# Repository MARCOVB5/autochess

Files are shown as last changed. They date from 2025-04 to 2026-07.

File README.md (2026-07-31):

# AutoChess

AutoChess é um protótipo de tabuleiro de MiniChess 4×4 capaz de jogar fisicamente
contra uma pessoa. O sistema combina visão computacional para reconhecer a jogada
humana, uma IA baseada em Q-learning para escolher a resposta e uma estrutura CNC
CoreXY com eletroímã para movimentar as peças.

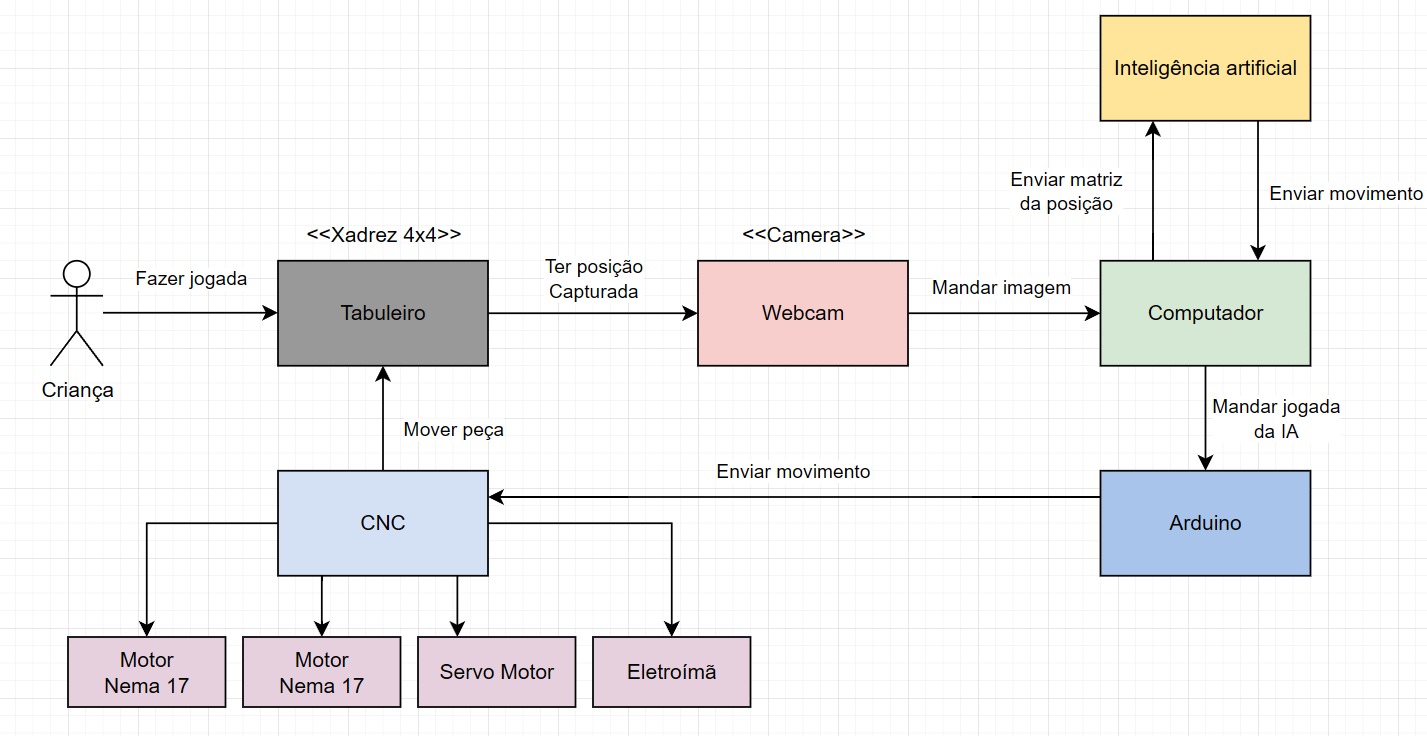
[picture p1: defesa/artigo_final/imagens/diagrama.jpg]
Diagrama geral do AutoChess


## Como funciona

O fluxo de uma partida é:

1. a pessoa movimenta uma peça branca no tabuleiro;
2. a câmera captura uma imagem do estado atual;
3. o módulo de visão computacional identifica as peças e deduz a jogada;
4. o motor de MiniChess valida o movimento;
5. a IA escolhe uma jogada para as peças pretas;
6. o controlador converte a jogada em comandos para a CNC, que move a peça.

O jogo utiliza um tabuleiro 4×4 com peões, torres, rainhas e reis. As peças brancas
são controladas pela pessoa e as pretas pela IA.

## Componentes

- **Motor de jogo:** regras, validação de jogadas, xeque, xeque-mate e empate.
- **Inteligência artificial:** agente de Q-learning tabular com avaliação heurística
  de uma jogada.
- **Visão computacional:** OpenCV para localizar o tabuleiro e classificar as peças.
- **Controle físico:** comunicação serial com Arduino e envio de comandos G-code.
- **Simuladores:** interfaces gráficas em Pygame para partidas locais, com ou sem IA.
- **Estrutura mecânica:** modelos do tabuleiro, peças e componentes para fabricação.

## Estrutura do repositório

```text
.
├── core/                         # Aplicação integrada e módulos principais
│   ├── main.py                   # Fluxo câmera → IA → CNC
│   ├── unified_app.py            # Painel visual integrado do robô
│   ├── button_reader.py          # Eventos dos botões físicos
│   ├── hardware_config.py        # Câmera, serial, comandos e coordenadas físicas
│   ├── minichess.py              # Regras do MiniChess 4×4
│   ├── ai_player.py              # Agente de Q-learning
│   ├── train_ai.py               # Treinamento da IA por simulação
│   ├── cv/                       # Visão computacional e imagens de treino/teste
│   ├── models/                   # Modelo persistido da IA
│   └── serial_cnc/               # Controlador serial e firmware do Arduino
├── minichess_simulator/
│   ├── minichess/                # Simulador pessoa contra pessoa
│   └── minichess_ia/             # Simulador pessoa contra IA
├── modelos/                      # Arquivos 3D e modelos do tabuleiro
├── proposta/                     # Propostas e documentação do projeto
└── defesa/                       # Artigo, apresentação e vídeo
```

## Requisitos

Para executar o software:

- Python 3;
- uma webcam compatível com OpenCV;
- Arduino conectado por USB e programado com o firmware do projeto;
- mecanismo CNC/CoreXY com servo e eletroímã.

Os simuladores gráficos não precisam do hardware físico.

## Instalação

Clone o repositório e crie um ambiente virtual:

```bash
git clone <URL-DO-REPOSITORIO>
cd autochess
python3 -m venv .venv
source .venv/bin/activate
python -m pip install --upgrade pip
python -m pip install -r core/requirements.txt
```

No Windows, ative o ambiente com:

```powershell
.venv\Scripts\activate
```

## Executando o sistema completo

Conecte a câmera e o Arduino, posicione o mecanismo na origem configurada e execute
a aplicação a partir da pasta `core`:

```bash
cd core
python main.py
```

A aplicação procura automaticamente a CNC nas portas seriais disponíveis. Índice e
orientação da câmera, porta serial, comandos do firmware, velocidade e coordenadas
da CNC ficam centralizados em `core/hardware_config.py`. Use `SERIAL_PORT = None`
para autodetecção ou informe explicitamente uma porta como `/dev/ttyUSB0` ou
`COM3`.

Durante a partida, use:

- `0` para capturar e processar a jogada;
- `1` para iniciar uma nova partida;
- `2` para apagar o aprendizado salvo e reiniciar a IA;
- `q` para encerrar.

### Painel unificado

O painel reúne o tabuleiro lógico, a última imagem processada pelo CV, a IA, a
CNC e os botões físicos:

```bash
cd core
python unified_app.py
```

Configure `SERIAL_PORT` para a CNC e `BUTTONS_SERIAL_PORT` para o Arduino dos
botões em `hardware_config.py`. As portas devem ser diferentes. Os botões enviam
`BUTTON_0`, `BUTTON_1` e `BUTTON_2`; mouse e teclado executam os mesmos comandos.

Para testar toda a interface e jogar contra a IA sem hardware:

```bash
python unified_app.py --simulate
```

Também é possível abrir uma imagem no painel de CV durante a simulação:

```bash
python unified_app.py --simulate \
  --cv-image cv/assets/storage/testing-chessboards/chessboard_allpieces.jpg
```

Use `--no-camera`, `--no-cnc` ou `--no-buttons` para testar apenas partes da
montagem.

> **Atenção:** antes do primeiro movimento, confira a origem, os limites e o sentido
> dos eixos da CNC. Revise `core/hardware_config.py` sempre que mudar a montagem,
> a câmera ou o firmware.

## Executando os simuladores

### Pessoa contra pessoa

```bash
cd minichess_simulator/minichess
python -m pip install -r ../../core/requirements.txt
python main.py
```

### Pessoa contra IA

```bash
cd minichess_simulator/minichess_ia
python -m pip install -r requirements.txt
python main.py
```

Nas interfaces, selecione uma peça com o mouse e clique em uma das casas destacadas
para realizar a jogada.

## Treinando a IA

O agente pode ser treinado sem câmera ou CNC, enfrentando um oponente aleatório:

```bash
cd core
python train_ai.py --games 1000 --seed 0
```

Por padrão, o modelo é salvo em `core/models/minichess_ai_model.pkl`. Use
`--model caminho/do/modelo.pkl` para escolher outro arquivo e `--max-plies` para
limitar a duração de cada partida simulada.

## Testes

Os testes do motor, da IA e do painel usam `unittest`:

```bash
cd core
python -m unittest test_ai.py test_unified_app.py
```

Também há scripts experimentais de câmera, visão e CNC em `core/test_*.py`,
`core/cv/` e `core/serial_cnc/`. Alguns deles dependem do hardware conectado e da
calibração do protótipo.

## Firmware

Os sketches usados pelo controlador estão em:

- `core/serial_cnc/arduino-cli/firmware_hibrido/firmware_hibrido.ino`;
- `core/serial_cnc/arduino-cli/grblUpload/grblUpload.ino`.

Grave no Arduino o firmware adequado à montagem antes de iniciar a aplicação
integrada. A comunicação serial utiliza `115200` baud por padrão.

## Documentação e materiais

- Artigo final: `defesa/artigo_final/output/main.pdf`;
- apresentação: `defesa/apresentacao/main.pdf`;
- vídeo do projeto: `defesa/video/video_autochess.mp4`;
- modelos para fabricação: `modelos/`.

## Estado do projeto

Este repositório contém um protótipo acadêmico. A precisão da visão computacional e
as coordenadas da CNC dependem da iluminação, do posicionamento da câmera e da
calibração mecânica de cada montagem.

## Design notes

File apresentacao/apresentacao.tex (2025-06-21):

\documentclass{beamer}

\usetheme{Madrid}  % Claro, limpo e com bom contraste

\usepackage[utf8]{inputenc}
\usepackage[absolute,overlay]{textpos} % no preâmbulo
\usepackage[T1]{fontenc}
\usepackage[brazil]{babel}
\usepackage{graphicx}
\usepackage[linesnumbered]{algorithm2e} % sem ruled, sem vlined
\usepackage{tikz}
\usetikzlibrary{shapes.geometric, arrows.meta, positioning}
\tikzstyle{startstop} = [rectangle, rounded corners, minimum width=2.8cm, minimum height=1cm,text centered, draw=black, fill=blue!20]
\tikzstyle{process} = [rectangle, minimum width=2.8cm, minimum height=1cm, text centered, draw=black, fill=gray!10]
\tikzstyle{decision} = [diamond, minimum width=3cm, minimum height=1cm, text centered, draw=black, fill=orange!20]
\tikzstyle{arrow} = [thick, ->, >=stealth]

\setbeamertemplate{footline}[frame number] % Numeração dos slides
\setbeamertemplate{navigation symbols}{}    % Remove os ícones padrão do Beamer

\title{Autochess}
\author{Fernando F. Vieira \\ Gabriel A. B. Caballero \\ Marco V. Busetti}
\institute{Oficina de Integração 1 (ELEX20) \\ Engenharia de Computação - UTFPR}
\date{\today}

% Configura aparência das páginas de seção
\AtBeginSection[]{
  \begin{frame}[plain]
    \frametitle{\insertsectionhead}
    \tableofcontents[currentsection]
  \end{frame}
}

\begin{document}

% Slide de capa
\frame{\titlepage}

% (Opcional) Índice da apresentação
\begin{frame}{Roteiro da Apresentação}
  \tableofcontents
\end{frame}

\section{Introdução}

\begin{frame}{Escopo e Objetivos}
\begin{itemize}
    \item O projeto \textbf{Autochess} foi desenvolvido com propósito pedagógico: introduzir conceitos de \textbf{Machine Learning} e \textbf{xadrez} para crianças.
    
    \item Utiliza um \textbf{tabuleiro 4x4} simplificado, composto por:
        \begin{itemize}
        \item Módulo de \textbf{Inteligência Artificial}.
        \item Módulo de \textbf{Visão Computacional}.
        \item Sistema \textbf{CNC}.
    \end{itemize}
\end{itemize}
\end{frame}

\begin{frame}[plain]{Diagrama de blocos}
  \centering

\end{frame}

\begin{frame}[plain]{Idealização do projeto}
  \centering
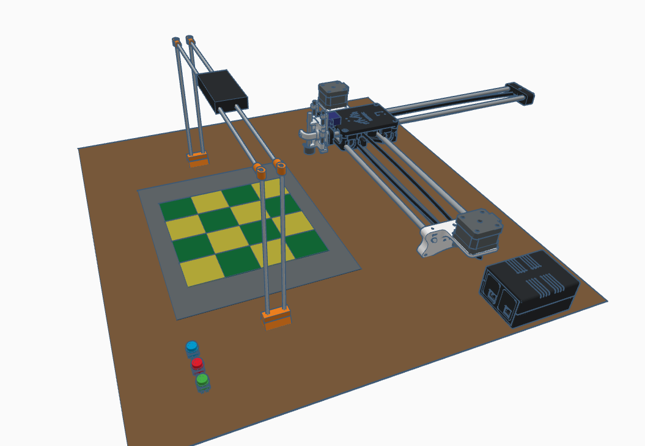
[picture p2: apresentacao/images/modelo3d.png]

\end{frame}

\begin{frame}{Materiais e Orçamento}
  \begin{tabular}{|l|c|c|}
    \hline
    \textbf{Item} & \textbf{Quantidade} & \textbf{Preço (R\$)} \\
    \hline
    Arduino Uno & 2 & 40,00 \\
    Shield CNC V3 + Drivers & 1 & 15,00 \\
    Eletroimã & 1 & 6,00 \\
    Nema 17 & 2 & 40,00 \\
    Servo motor SG90 & 1 & 5,00 \\
    Placa universal & 1 & 12,00 \\
    Patolas & 2 & 30,00 \\
    Fonte de alimentação & 2 & 50,00 \\
    Webcam Full HD & 1 & 50,00 \\
    Impressão 3D & - & 100,00 \\
    Base MDF & - & 40,00 \\
    Outros (fios, conectores, etc) & - & 30,00 \\
    \hline
    \textbf{Total} & & \textbf{418,00} \\
    \hline
  \end{tabular}
   \vspace{0.5em}

  {\scriptsize\textit{Observação: Componentes eletrônicos adquiridos via \href{https://pt.aliexpress.com}{AliExpress}.}}
\end{frame}

% Seção 1
\section{Hardware}

\begin{frame}[plain]{Idealização do projeto elétrico}
  \centering
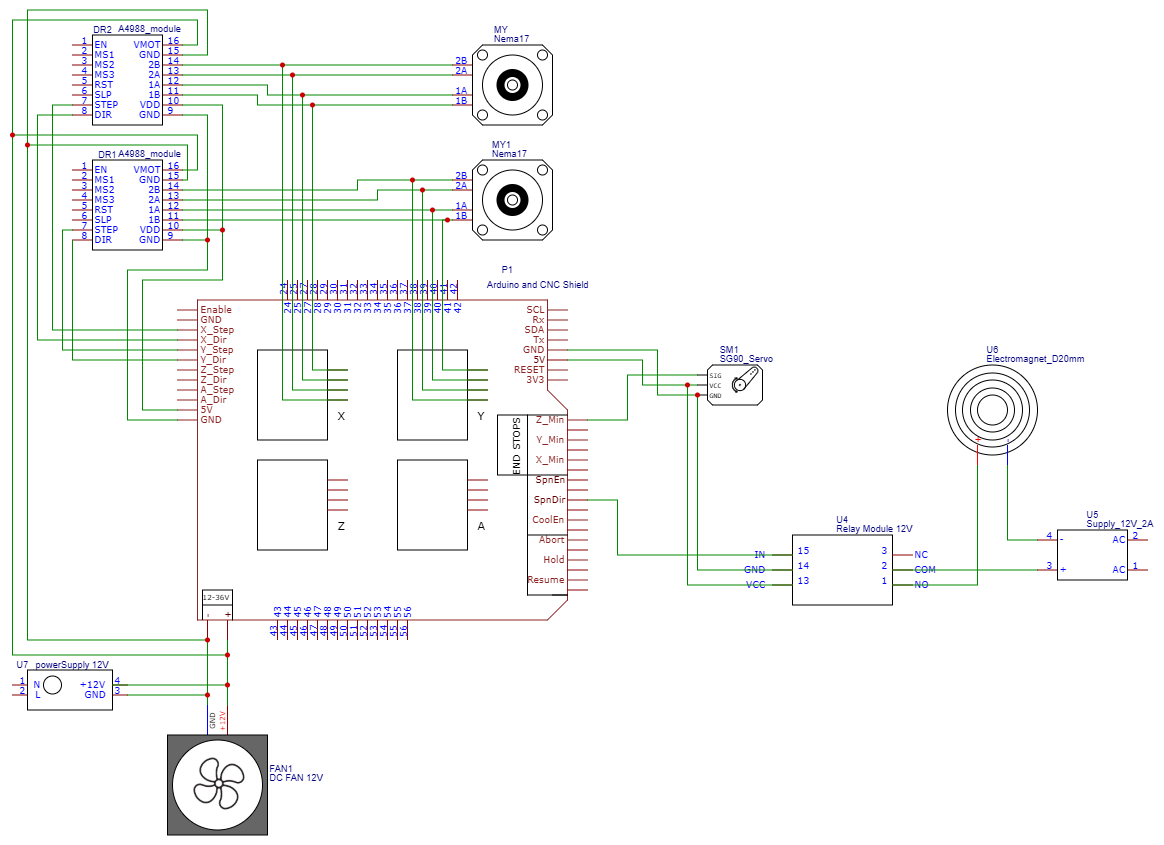
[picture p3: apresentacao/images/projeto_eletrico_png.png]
  
\end{frame}

\begin{frame}[plain]{Idealização do projeto elétrico}
  \centering
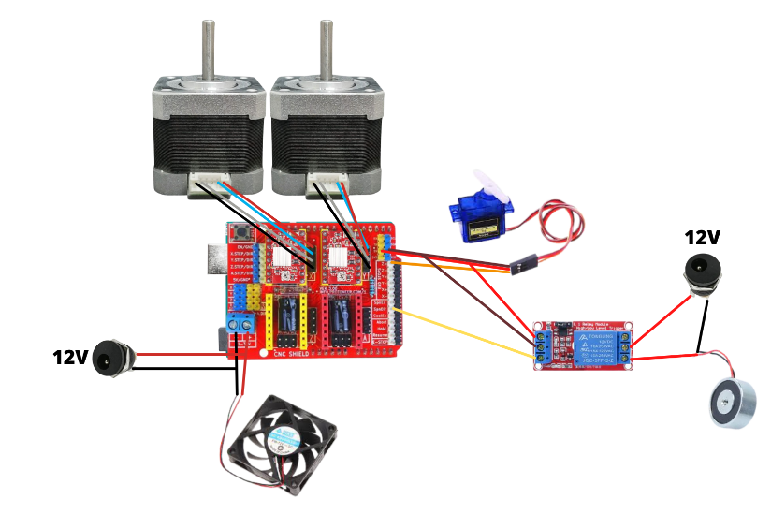
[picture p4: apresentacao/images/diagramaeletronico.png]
  
\end{frame}

\begin{frame}[plain]{Algumas modificações...}
\begin{itemize}
    \item Foram utilizados \textbf{2 Arduinos UNO}.
    \item Tarefas de cada um:
    \begin{itemize}
        \item \textbf{Arduino 1}: Controle da CNC (\textit{firmware} GRBL-servo);
        \item \textbf{Arduino 2}: Receber input dos botões.
    \end{itemize}
\end{itemize}
\end{frame}

\begin{frame}{Controle e Firmware}
  \begin{itemize}
    \item Utilizado o \textbf{firmware GRBL-servo}, baseado no repositório da \textbf{Robottini}\textsuperscript{\ref{grbl-servo-link}}.
    \item GRBL é um firmware open-source que interpreta comandos \texttt{G-code} para controle de CNCs.
    \item Permitiu o \textbf{controle dos motores de passo}, \textbf{eletroímã} e \textbf{servomotor} com precisão.
    \item Foram realizadas algumas modificações no código fonte do firmware para adaptar o ângulo de abertura do servomotor.
  \end{itemize}

  \vfill
  \begin{flushright}
    \scriptsize \textsuperscript{\refstepcounter{footnote}\label{grbl-servo-link}\thefootnote} \href{https://github.com/robottini/grbl-servo}{https://github.com/robottini/grbl-servo}
  \end{flushright}
\end{frame}

% Seção 3
\section{Mecânica}

\begin{frame}{Estrutura CoreXY}
  \begin{figure}
    \centering
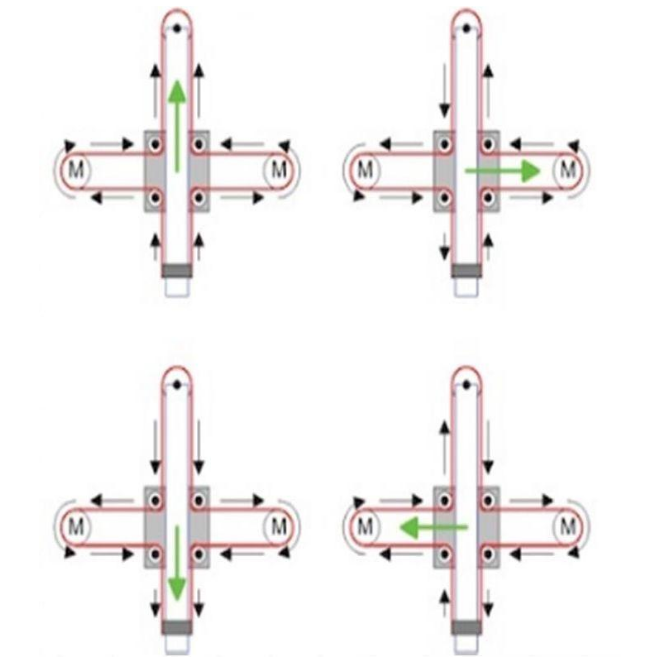
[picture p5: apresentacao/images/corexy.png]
    
    \caption{Estrutura cruzada CoreXY}
      \vspace{0.3em}
  {\small \textit{Fonte:} \href{test3dprints.com}{test3dprints.com}}
    \label{fig:enter-label}
\end{figure}
\end{frame}

\begin{frame}{CoreXY - Princípio de Funcionamento}
\begin{itemize}
  \item Os motores estão fixos na estrutura.
  \item O movimento é transmitido por apenas uma correia e polias dispostas em padrão cruzado.
  \item Os motores atuam juntos para gerar os deslocamentos nos eixos.
\end{itemize}
\end{frame}

\begin{frame}{Vantagens do CoreXY}
\begin{itemize}
  \item Cabeçote leve (motores não se movem junto).
  \item Alta velocidade e aceleração.
  \item Estrutura simétrica e eficiente no uso do espaço.
  \item Redução de inércia no movimento.
  \item Uso de apenas uma correia.
\end{itemize}
\end{frame}

\begin{frame}{Estrutura física do projeto}
  \begin{itemize}
    \item Para o suporte da CNC foi utilizado como base o projeto \textbf{DrawingBot} da \textbf{MakerC}\textsuperscript{\ref{drawingbot-link}}.
    \item Arquivos para impressão 3D disponibilizados foram utilizados.
    \item Todos os objetos são apoiados em uma base de MDF cortada à laser.
    \item Fora a estrutura impressa 3D da CNC (já pronta), todos os outros objetos (peças de xadrez, suporte para câmera, etc.) foram modelados à parte.
  \end{itemize}

  \vfill
  \begin{flushright}
    \scriptsize \textsuperscript{\refstepcounter{footnote}\label{drawingbot-link}\thefootnote} \href{https://www.thingiverse.com/thing:1517211}{https://www.thingiverse.com/thing:1517211}
  \end{flushright}
\end{frame}

\begin{frame}{Modelo da base do MDF}
  \centering
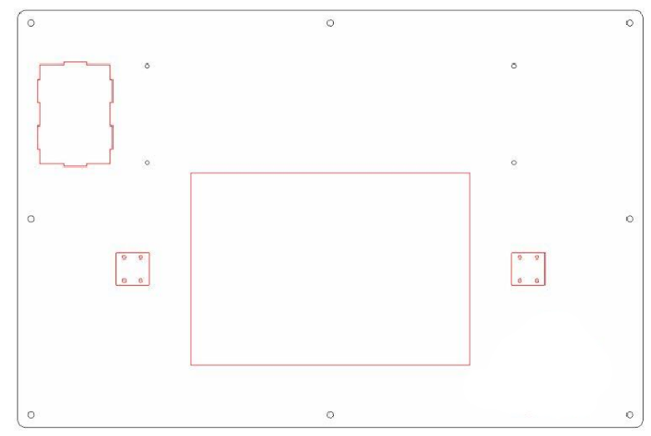
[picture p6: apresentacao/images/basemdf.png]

\end{frame}

\begin{frame}{Modelos 3D - suporte para câmera}
  \centering
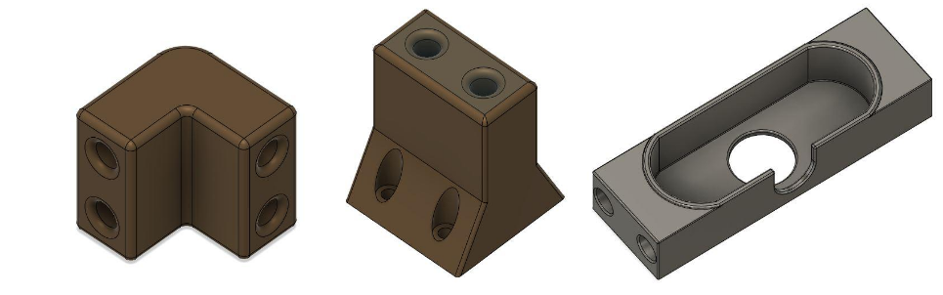
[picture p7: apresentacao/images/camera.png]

\end{frame}

\begin{frame}{Modelos 3D - peças do xadrez}
  \centering
  \begin{minipage}{0.48\textwidth}
    \centering
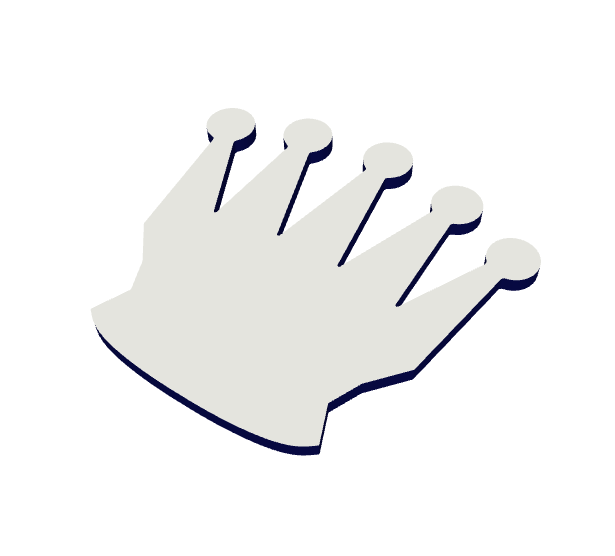
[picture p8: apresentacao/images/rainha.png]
    
    \caption{Rainha}
  \end{minipage}
  \hfill
  \begin{minipage}{0.48\textwidth}
    \centering
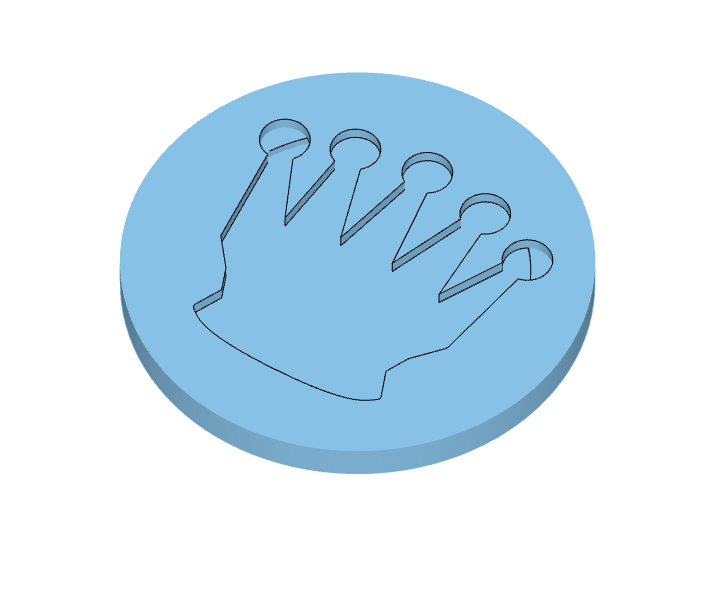
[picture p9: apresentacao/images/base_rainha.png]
    
    \caption{Base da Rainha}
  \end{minipage}
\end{frame}

\section{Software}

\begin{frame}{Minichess 4×4 – Variante Silverman}
\begin{itemize}
  \item \textbf{Minichess} é uma \textbf{família de variantes} do xadrez tradicional, jogadas em tabuleiros menores.
  \item A variante \textbf{Silverman 4×4} é jogada com as seguintes peças:
  \begin{itemize}
    \item Rei, torre, rainha e peões.
  \end{itemize}
  \item Útil para estudo de algoritmos, resolução de jogos e IA aplicada.
\end{itemize}
\end{frame}

\begin{frame}{Minichess 4×4 – Variante Silverman}
  \begin{figure}
    \centering
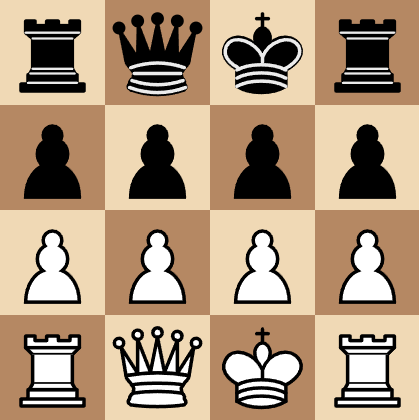
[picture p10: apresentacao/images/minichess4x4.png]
    
    \caption{Silverman 4x4}
      \vspace{0.3em}
  {\small \textit{Fonte:} \href{https://en.wikipedia.org/wiki/Minichess}{https://en.wikipedia.org/wiki/Minichess}}
    \label{fig:enter-label}
\end{figure}
\end{frame}

\begin{frame}{IA com Q-Learning no Silverman 4×4}
\begin{itemize}
  \item Modelamos o jogo como um \textbf{Processo de Decisão de Markov (MDP)}:
  \begin{itemize}
    \item \textbf{Estados} (\( S \)): todas as possíveis configurações do tabuleiro.
    \item \textbf{Ações} (\( A \)): todos os movimentos legais em um dado estado.
    \item \textbf{Recompensa} (\( R \)): +1 para vitória, 0 para empate, -1 para derrota.
  \end{itemize}
  \item Utilizamos \textbf{Q-Learning}, um algoritmo off-policy de aprendizagem por reforço:
  \[
  Q(s,a) \leftarrow Q(s,a) + \alpha \left[ r + \gamma \max_{a'} Q(s',a') - Q(s,a) \right]
  \]
  \item Estratégia \textbf{$\varepsilon$-gulosa} para equilibrar \textit{exploration \& exploitation}:
  \[
  \text{Escolhe melhor ação com probabilidade } 1 - \varepsilon, \text{ aleatória com } \varepsilon
  \]
\end{itemize}
\end{frame}

\begin{frame}{Parâmetros do Q-Learning e $\varepsilon$-gulosa}
\begin{itemize}
  \item \textbf{Taxa de aprendizado} \(\alpha\): \\
        \(\rightarrow\) Valor utilizado: \(\alpha = 0.5\).
  
  \item \textbf{Fator de desconto} \(\gamma\):  \\
        \(\rightarrow\) Valor utilizado: \(\gamma = 0.9\).
  
  \item \textbf{Taxa de exploração} \(\varepsilon\) (estratégia $\varepsilon$-gulosa): \\
        \(\rightarrow\) Inicialmente alta (ex: 0.9), decresce ao longo do treinamento para valores baixos (ex: 0.1 ou 0.01).
\end{itemize}
\end{frame}

\begin{frame}[fragile]{Q-Learning}
\begin{center}
\begin{minipage}{0.85\linewidth} % ajusta a largura do algoritmo
\begin{algorithm}[H]
\DontPrintSemicolon
\textcolor{blue}{\textbf{Inicializar}} $Q(s, a)$ arbitrariamente\;
\For{\textcolor{purple}{\textbf{cada episódio}} (partida)}{
    \textcolor{blue}{\textbf{Inicializar}} estado $s$\;
    \While{\textcolor{red}{\textbf{jogo não terminou}}}{
        \colorbox{yellow!20}{Com probabilidade $\varepsilon$, escolher ação aleatória $a$}\;
        \colorbox{yellow!20}{Caso contrário, escolher $a = \arg\max_{a'} Q(s, a')$}\;
        \textcolor{orange}{\textbf{Executar}} ação $a$, observar recompensa $r$ e novo estado $s'$\;
        \textcolor{green!60!black}{\textbf{Atualizar:}} \\
        \colorbox{green!15}{$Q(s,a) \leftarrow Q(s,a) + \alpha \left[ r + \gamma \max_{a'} Q(s',a') - Q(s,a) \right]$}\;
        $s \leftarrow s'$\;
    }
}
\end{algorithm}
\end{minipage}
\end{center}
\end{frame}

\begin{frame}{Q-Learning}
\begin{center}
\scalebox{0.8}{ % Reduz o tamanho geral do fluxograma
\begin{tikzpicture}[node distance=1.2cm and 1.7cm]
\tikzstyle{startstop} = [rectangle, rounded corners, minimum width=2.5cm, minimum height=0.9cm, text centered, draw=black, fill=blue!20, font=\small]
\tikzstyle{process}   = [rectangle, minimum width=2.5cm, minimum height=0.9cm, text centered, draw=black, fill=gray!10, font=\small]
\tikzstyle{decision}  = [diamond, minimum width=2.6cm, minimum height=0.9cm, text centered, draw=black, fill=orange!20, font=\small]
\tikzstyle{arrow}     = [thick, ->, >=stealth]

\node (start)  [startstop] {Início do Episódio};
\node (init)   [process, below of=start] {Inicializa $s$};
\node (check)  [decision, below of=init, yshift=-0.9cm] {Fim do jogo?};
\node (action) [process, right of=check, xshift=3.5cm] {Escolhe ação $a$};
\node (step)   [process, below of=action] {Executa $a$, observa $r$, $s'$};
\node (update) [process, below of=step] {Atualiza $Q(s,a)$};
\node (loop)   [process, below of=update] {$s \leftarrow s'$};
\node (end)    [startstop, below of=check, yshift=-3.8cm] {Fim do Episódio};

% Setas principais
\draw [arrow] (start) -- (init);
\draw [arrow] (init) -- (check);

% Seta "não" - usando anchors específicos para evitar sobreposição
\draw [arrow] (check.east) -- node[above] {\footnotesize não} (action.west);

% Setas do loop principal
\draw [arrow] (action) -- (step);
\draw [arrow] (step) -- (update);
\draw [arrow] (update) -- (loop);

% Seta de volta para o check - corrigindo direção da seta
\draw [arrow] (loop.west) -| ++(-4.5,2.4) -| (check.west);

% Seta "sim" - usando anchor específico
\draw [arrow] (check.south) -- node[right] {\footnotesize sim} (end.north);

\end{tikzpicture}
}
\end{center}
\end{frame}

\begin{frame}{Metodologia de Avaliação da IA}
  \begin{itemize}
    \item \textbf{Número de sessões:} 30 sessões distintas, com reinicialização da IA ao início de cada sessão.
    
    \item \textbf{Partidas por sessão:} 20 partidas sequenciais por sessão, totalizando \textbf{600 partidas analisadas}.

    \item \textbf{Métricas utilizadas:}
    \begin{enumerate}
      \item \textbf{Média de jogadas por partida;}
      \item \textbf{Número de blunders;}
      \item \textbf{Saldo de material;}
      \item \textbf{Jogadas seguras (\%).}
    \end{enumerate}
    \item Média de todas sessões de uma determinada partida.
  \end{itemize}
\end{frame}

\begin{frame}[plain]{Q-Learning - Levantamento estatístico sob os resultados}
  \centering
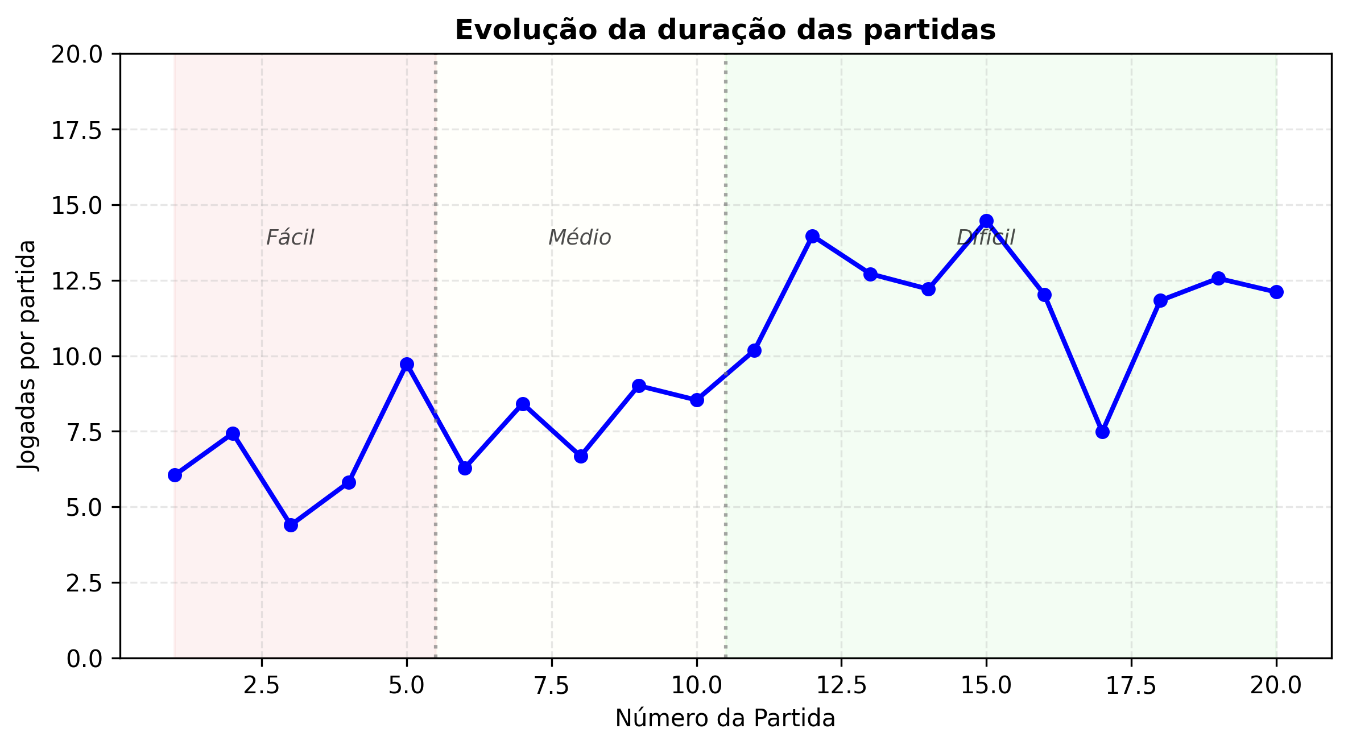
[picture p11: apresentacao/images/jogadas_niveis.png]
  
\end{frame}

\begin{frame}[plain]{Q-Learning - Levantamento estatístico sob os resultados}
  \centering
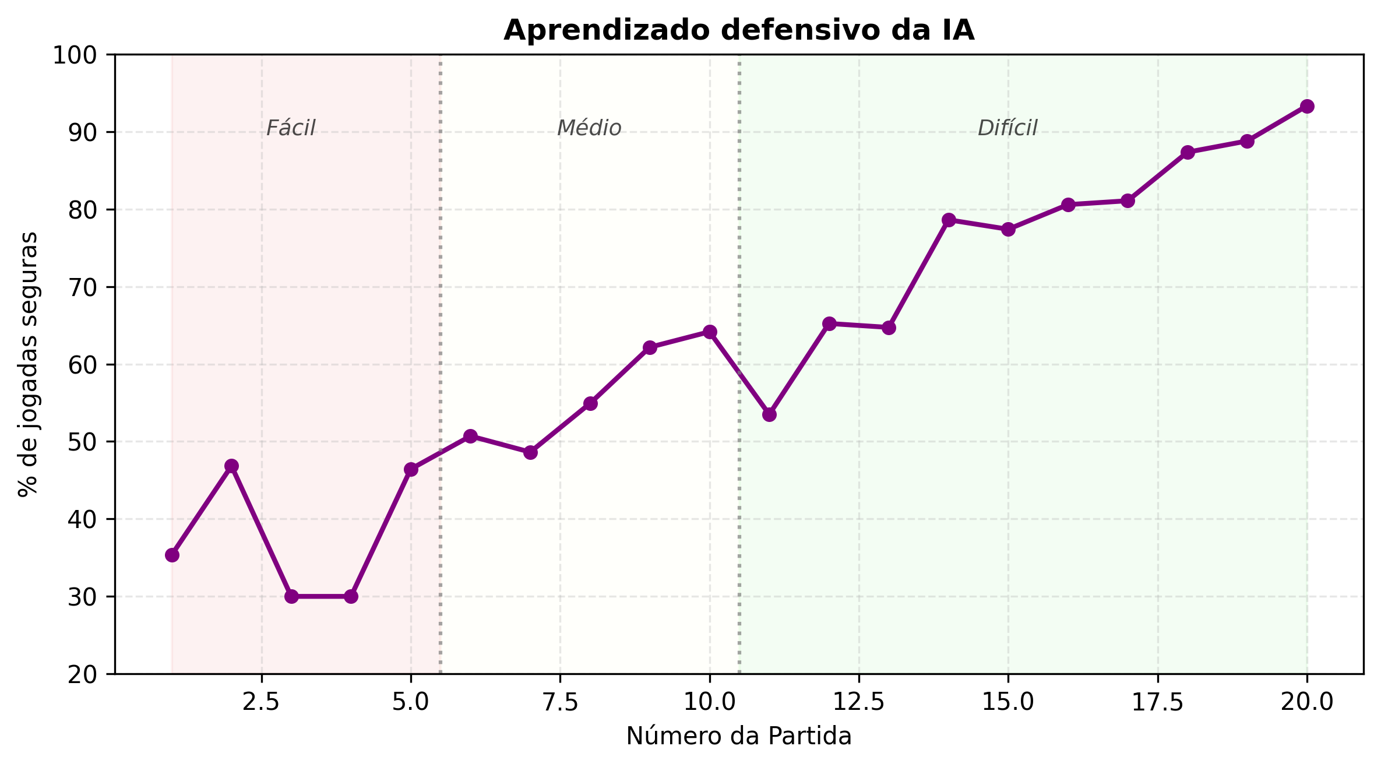
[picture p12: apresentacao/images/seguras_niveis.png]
  
\end{frame}

\begin{frame}[plain]{Q-Learning - Levantamento estatístico sob os resultados}
  \centering
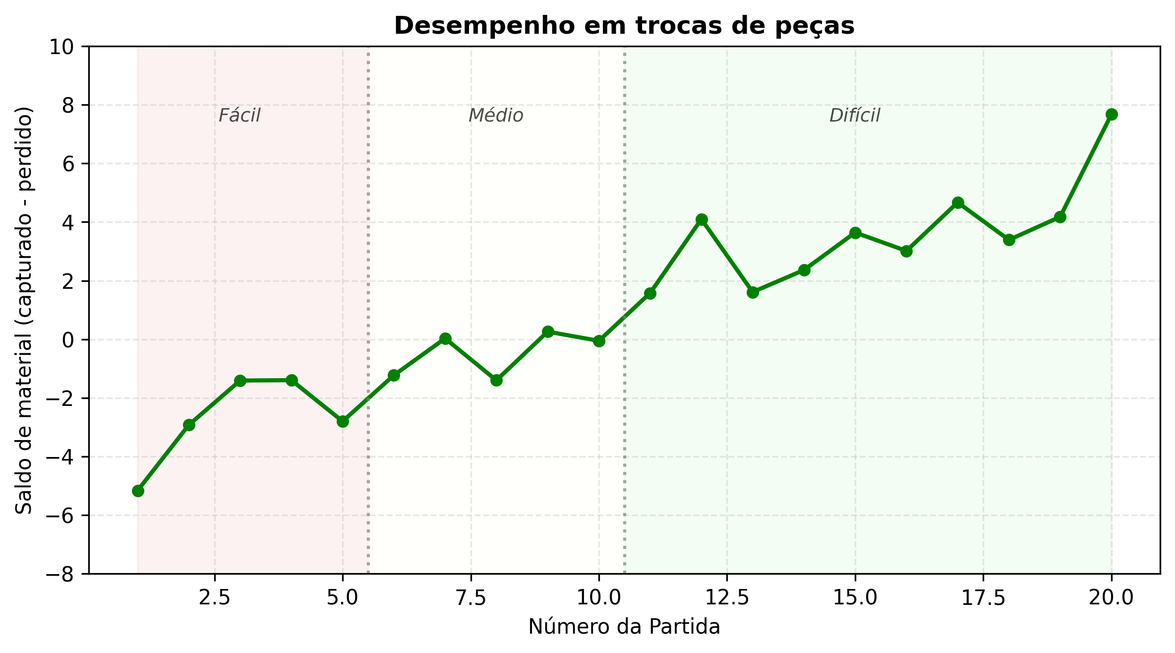
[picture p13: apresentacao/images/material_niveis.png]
  
\end{frame}

\begin{frame}[plain]{Q-Learning - Levantamento estatístico sob os resultados}
  \centering
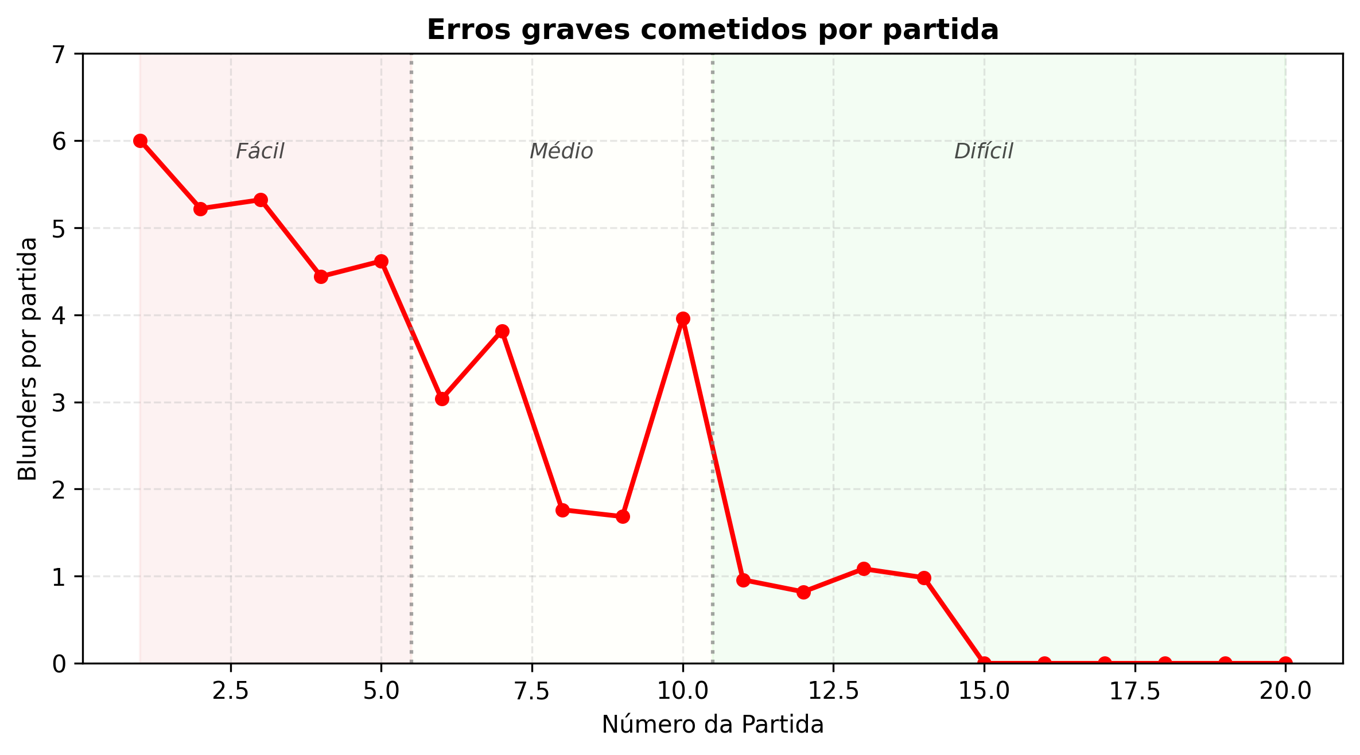
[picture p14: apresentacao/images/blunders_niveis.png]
  
\end{frame}

\begin{frame}{Visão Computacional}
\begin{itemize}
    \item Para identificar o estado do jogo automaticamente, foi necessário utilizar técnicas de visão computacional sobre imagens capturadas por uma câmera fixa.
\end{itemize}
\end{frame}

\begin{frame}{Visão Computacional}
      \begin{alertblock}{Desafios enfrentados}
          \begin{itemize}
        \item Segmentação precisa da área do tabuleiro, mesmo com distorções da câmera.
        \item Diferenciação entre peças brancas e pretas sob diferentes condições de iluminação.
        \item Identificação das peças no tabuleiro, considerando posições variadas.
    \end{itemize}    
  \end{alertblock}
\end{frame}

\begin{frame}{Visão Computacional}
  \begin{exampleblock}{Solução adotada}
        \begin{itemize}
        \item Utilizamos o \textbf{SIFT (Scale-Invariant Feature Transform)} para detecção de pontos-chave robustos.
        \item Detecção de contornos das figuras das peças e extremidades do tabuleiro.
        \item As descrições extraídas com SIFT permitiram realizar \textit{matching} entre peças reais e modelos de referência.
    \end{itemize}
  \end{exampleblock}

\end{frame}

\begin{frame}[plain]{Implementação do SIFT - Exemplos}
  \centering
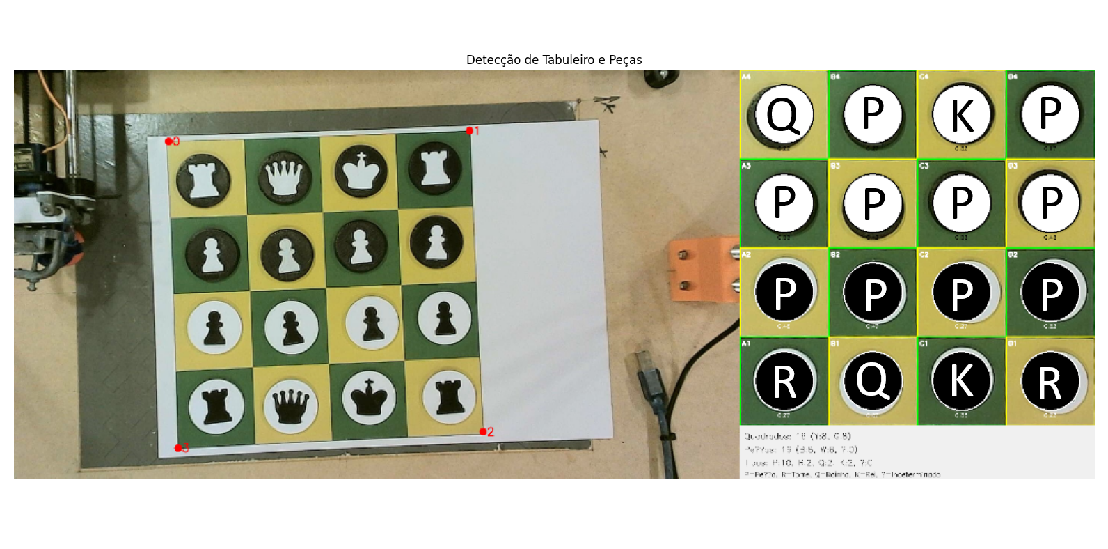
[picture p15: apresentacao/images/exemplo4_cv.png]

\end{frame}

\begin{frame}[plain]{Implementação do SIFT - Exemplos}
  \centering
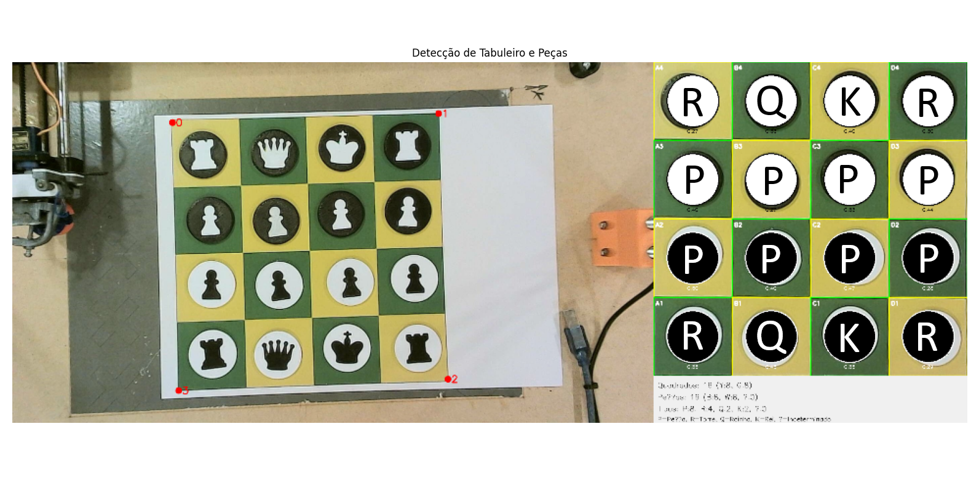
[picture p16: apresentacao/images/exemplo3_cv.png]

\end{frame}

\begin{frame}[plain]{Implementação do SIFT - Exemplos}
  \centering
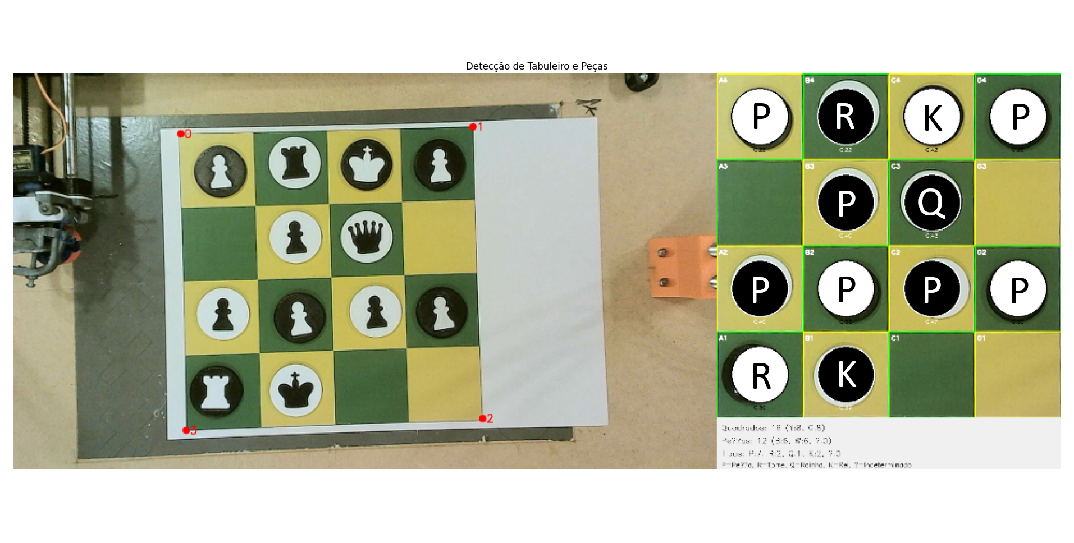
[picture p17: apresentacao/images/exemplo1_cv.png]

\end{frame}

\begin{frame}[plain]{Implementação do SIFT - Exemplos}
  \centering
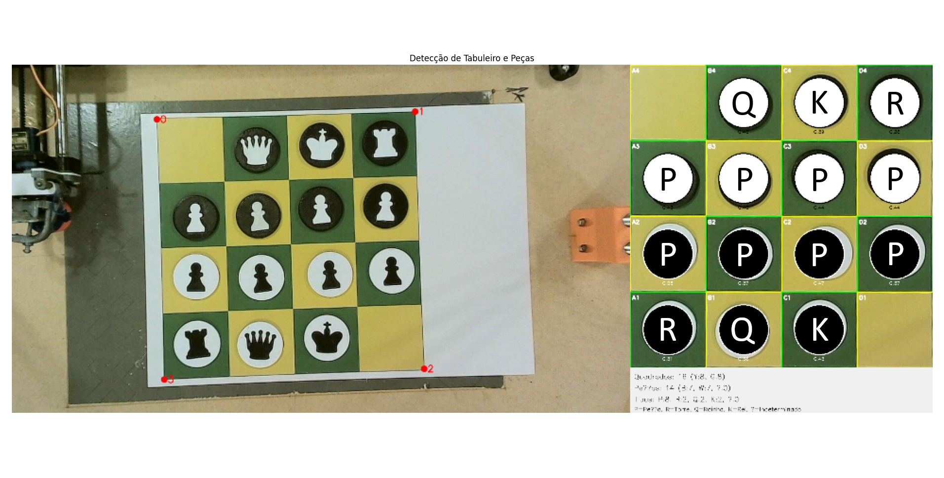
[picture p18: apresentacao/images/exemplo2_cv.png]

\end{frame}

\section{Resultados}

\begin{frame}{Resultados - decisões que funcionaram bem}
  \begin{itemize}
  \item \textbf{Hardware}:
        \begin{itemize}
            \item Comunicação serial bem sucedida: \textit{firmare} GRBL servo funcionou como deveria;
        \end{itemize}
    \item \textbf{Mecânica}:
        \begin{itemize}
            \item Estrutura do braço CNC forte e confiável;
            \item Peças de xadrez 3D respondendo perfeitamente às atrações magnéticas.
        \end{itemize}
    \item \textbf{Software}:
        \begin{itemize}
            \item Machine learning apresentou evolução com o decorrer das partidas;
            \item Visão Computacional confiável em diversas condições de luz e posições de peças.
        \end{itemize}
  \end{itemize}
\end{frame}

\begin{frame}{Resultados - problemas a serem melhorados}
  \begin{itemize}
  \item \textbf{Hardware}:
        \begin{itemize}
            \item Utilização de dois Arduinos para comunicação serial; 
        \end{itemize}
    \item \textbf{Mecânica}:
        \begin{itemize}
            \item Base MDF causando desníveis;
            \item Um motor de passo "mais lento" que o outro.
        \end{itemize}
    \item \textbf{Software}:
        \begin{itemize}
            \item Visão Computacional tomando muito tempo para processamento de tabuleiro cheio.
        \end{itemize}
  \end{itemize}
\end{frame}

\begin{frame}{Conclusão dos Resultados}
  \begin{itemize}
    \item O sistema funcionou bem como uma ferramenta prática e didática para apresentar aprendizado de máquina a um público infantil.

\item A experiência mostrou que a escolha das ferramentas e abordagens foi acertada:
\begin{itemize}
  \item O uso do GRBL com Arduinos se provou uma solução estável e prática;
  \item A estrutura mecânica funcionou como esperado, e as peças responderam bem ao controle magnético;
  \item A IA conseguiu aprender com poucas partidas, o que validou a proposta de demonstrar aprendizado de máquina de forma acessível e dinâmica;
  \item A visão computacional se manteve confiável mesmo com variações de luz e disposição das peças.
\end{itemize}

  \end{itemize}
\end{frame}

\begin{frame}{Próximos Passos}
  \begin{itemize}
    \item Melhorar a estrutura da base para evitar desníveis;
    \item Unificar o controle em um único microcontrolador;
    \item Otimizar a visão computacional para situações com muitas peças.
  \end{itemize}
\end{frame}

\begin{frame}[plain]
  \frametitle{Muito obrigado!}

  \vspace{1.5cm}
  \centering
  \Huge Muito obrigado pela atenção!

\end{frame}

\end{document}

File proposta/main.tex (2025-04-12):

\documentclass[a4paper,12pt]{article}
\usepackage[utf8]{inputenc}           % Codificação de entrada
\usepackage[T1]{fontenc}              % Codificação de fonte
\usepackage{lmodern}                  % Fonte moderna
\usepackage{xcolor}                   % Gerenciamento de cores
\usepackage{graphicx}                 % Inclusão de gráficos
\usepackage{hyperref}                 % Hyperlinks
\usepackage{amsmath}                  % Fórmulas matemáticas
\usepackage{geometry}                 % Configuração das margens
\usepackage{titling}                  % Customização de títulos
\usepackage{float}                    % Controle de posição de figuras
\usepackage{titlesec}                 % Customização dos títulos de seções
\usepackage{fancyhdr}                 % Cabeçalho e rodapé customizados
\usepackage[portuguese]{babel}        % Suporte ao português

% Configuração da geometria da página
\geometry{top=2cm, bottom=2cm, left=3cm, right=3cm}

% Configuração do hyperref
\hypersetup{
    colorlinks=true,
    linkcolor=blue,
    urlcolor=blue
}

% Configuração do cabeçalho e rodapé usando fancyhdr
\pagestyle{fancy}
\fancyhf{}
\fancyhead[L]{Universidade Tecnológica Federal do Paraná}
\fancyhead[R]{Oficina de Integração 1}
\fancyfoot[C]{\thepage}
\renewcommand{\headrulewidth}{0.4pt}
\renewcommand{\footrulewidth}{0.4pt}

% Customização dos títulos das seções com titlesec
\titleformat{\section}
  {\normalfont\Large\bfseries\color{}}{\thesection}{1em}{}
\titleformat{\subsection}
  {\normalfont\large\bfseries\color{}}{\thesubsection}{1em}{}

% Título, autores e data
\title{\textbf{Minichess 4x4 com Machine Learning e Sistema CNC}}
\author{%
    \textbf{Fernando Frare Vieira} \\
    fernandofrarevieira@alunos.utfpr.edu.br \\[1.5em]
    \textbf{Gabriel Affonso Borges Caballero} \\
    gabrielaffonso@alunos.utfpr.edu.br \\[1.5em]
    \textbf{Marco Vieira Busetti} \\
    marcovieirabusetti@alunos.utfpr.edu.br
}
\date{\today}

\begin{document}

\vspace{1em}

\begin{center}
    \Large\textbf{Minichess com Machine Learning \\e Sistema CNC}
\end{center}

\vspace{1em}

% Autores e contatos
\begin{center}
    \textbf{Fernando Frare Vieira} \\
    fernandofrarevieira@alunos.utfpr.edu.br \\[1.5em]
    \textbf{Gabriel Affonso Borges Caballero} \\
    gabrielaffonso@alunos.utfpr.edu.br \\[1.5em]
    \textbf{Marco Vieira Busetti} \\
    marcovieirabusetti@alunos.utfpr.edu.br
\end{center}

\vspace{2em}

\begin{center}
    \today
\end{center}

\vspace{2em}

\section{Introdução}
O projeto "Minichess com Machine Learning e Sistema CNC" \;foi desenvolvido com o propósito pedagógico de introduzir conceitos de Machine Learning para crianças. Utilizando um tabuleiro de xadrez simplificado (4x4), o sistema integra componentes de Inteligência Artificial e automação para demonstrar, de forma lúdica, como o aprendizado de máquina pode ser aplicado na prática. A solução proposta conta com um módulo de Visão Computacional, que realiza a captura do tabuleiro físico, e com um sistema CNC, que executa a movimentação automatizada das peças através da comunicação entre um computador e um Arduino.

\section{Motivação}
O principal objetivo deste projeto é educar crianças sobre os fundamentos do Machine Learning, uma área de extrema relevância na atualidade, por meio de uma experiência interativa e prática. Além disso, o Minichess 4x4 visa estimular o desenvolvimento do raciocínio lógico e da tomada de decisão, utilizando o xadrez simplificado como ferramenta de aprendizado. A integração dos componentes físicos (tabuleiro e sistema CNC) com a Inteligência Artificial oferece um ambiente dinâmico, onde o aluno interage diretamente com o jogo, consolidando os conceitos através da prática.

\section{Descrição Geral}
O Minichess 4x4 foi concebido para funcionar de forma integrada, utilizando um computador, uma câmera e um sistema CNC. Diferente de soluções que operam apenas por meio de interfaces gráficas, o jogo é realizado de modo físico: a criança posiciona as peças no tabuleiro real e o sistema, por meio da captura de imagem, interpreta a configuração atual e, em conjunto com a Inteligência Artificial, toma a decisão sobre o movimento. Posteriormente, o sistema CNC, controlado via comunicação serial com o Arduino, efetua a movimentação física das peças. Essa abordagem garante uma experiência completa e interativa, unindo teoria e prática. 

A integração é realizada através de APIs desenvolvidas em Python, utilizando o framework Flask para comunicação entre os módulos de Visão Computacional, Inteligência Artificial e controle CNC. O sistema CNC é baseado em um manipulador cartesiano com três graus de liberdade (eixos X, Y e Z), utilizando motores de passo Nema 17 em configuração CoreXY para movimentação precisa no plano horizontal, e um servo motor SG90 para controle vertical do eletroímã responsável pela movimentação das peças.

\section{Diagrama de Blocos}
\begin{figure}[H]
    \centering
     % Atualize o caminho para a imagem correspondente
    \caption{Diagrama de Blocos do Sistema Minichess}
    \label{fig:diagrama}
\end{figure}

\clearpage
\vspace{1em}

\section{Descrição do Software}
O software deste projeto é responsável por:
\begin{itemize}
    \item Implementar a lógica do jogo e a Inteligência Artificial com Machine Learning, utilizando o algoritmo \textbf{Q-learning} (aprendizado por reforço) para tomada de decisão. O agente aprende a otimizar suas jogadas através de um processo iterativo, onde cada ação é associada a um valor (*Q-value*) que representa a recompensa esperada em longo prazo. O algoritmo equilibra exploração (testar novas jogadas) e exploração (usar conhecimento adquirido), ajustando-se dinamicamente conforme interage com o jogador. A função de recompensa é definida para priorizar vitórias, evitar derrotas e incentivar movimentos estratégicos no tabuleiro 4x4.
    
    \item Capturar e processar imagens do tabuleiro físico utilizando a biblioteca OpenCV. As técnicas incluem detecção de cores (espaço HSV), filtragem de bordas (Canny) e comparação de contornos para identificar a posição das peças. A imagem é recortada para isolar o tabuleiro e evitar interferências externas.
    
    \item Gerenciar a comunicação entre o computador e o Arduino via protocolo serial, enviando comandos em G-Code para controle do sistema CNC. Uma API REST (desenvolvida com Flask) coordena o fluxo entre os subsistemas: após a jogada do usuário, a visão computacional envia o estado do tabuleiro para a IA, que retorna a ação aprendida pelo Q-learning, convertida em coordenadas para movimentação física pelo CNC.
\end{itemize}

\section{Descrição do Hardware}
Para a realização do jogo físico, o sistema conta com os seguintes componentes de hardware:
\begin{itemize}
    \item \textbf{Computador com Câmera:} Utilizado para capturar imagens do tabuleiro (resolução 1920x1080) e processar as informações necessárias para a tomada de decisão. A câmera é fixada em uma estrutura de suporte 3D impressa, posicionada verticalmente para garantir visibilidade total do tabuleiro.
    \item \textbf{Arduino UNO com CNC Shield V3:} Responsável por controlar os motores de passo (Nema 17) e o servo motor SG90. A CNC Shield utiliza drivers A4988 configurados em modo 1/4 de passo para equilibrar velocidade e precisão, e um relé JQC-3FF-S-Z para acionamento do eletroímã de 12V.
    \item \textbf{Sistema CNC CoreXY:} Composto por dois motores de passo para movimento no plano XY, seguindo o arranjo CoreXY para reduzir a inércia. O eixo Z é controlado por um servo motor, responsável por abaixar e levantar o eletroímã. A estrutura mecânica é baseada em perfis de MDF cortados a laser, com correias sincronizadas para transmissão de movimento.
    \item \textbf{Fonte de Alimentação:} Duas fontes de 12V 5A são utilizadas: uma para os motores de passo e ventoinhas de refrigeração, e outra exclusiva para o eletroímã.
\end{itemize}

\begin{figure}[H]
    \centering
     % Atualize com o caminho da imagem do modelo 3D ou do esquemático do CNC
    \caption{Referência do sistema CNC para movimentação física}
    \label{fig:modelo_cnc}
\end{figure}

\section{Lista de Componentes}
\begin{itemize}
    \item \textbf{Software:}
    \begin{itemize}
        \item Python 3.8+ (com bibliotecas OpenCV, Flask, NumPy, e PySerial)
        \item Firmware GRBL (para interpretação de G-Code no Arduino)
    \end{itemize}
    \item \textbf{Hardware:}
    \begin{itemize}
        \item Computador com câmera USB Full HD
        \item Arduino UNO + CNC Shield V3 + Drivers A4988
        \item 2x Motores de Passo Nema 17 + Correias GT2
        \item Servo Motor SG90 + Eletroímã 12V
        \item Fonte de Alimentação 12V 5A (2 unidades)
        \item Estrutura em MDF cortada a laser + Suportes 3D impressos
    \end{itemize}
\end{itemize}

\section{Integração entre Software e Hardware}
A comunicação entre os módulos é realizada através de APIs desenvolvidas em Flask, garantindo modularidade e escalabilidade. O fluxo segue três etapas:
\begin{enumerate}
    \item \textbf{Visão Computacional:} Após a jogada do usuário, a câmera captura uma imagem, processada pelo OpenCV para gerar uma matriz 4x4 representando o tabuleiro.
    \item \textbf{Inteligência Artificial:} A matriz é enviada para a API da IA, que executa o algoritmo de IA e retorna a coordenada jogada.
    \item \textbf{Controle CNC:} A coordenada é convertida em comandos G-Code (e.g., \texttt{G0 X10 Y5}) e enviada ao Arduino via serial. O CNC move o eletroímã até a peça, a transporta para a nova posição e retorna à origem.
\end{enumerate}

\vspace{1em}

\section{Cronograma}
\begin{figure}[H]
    \centering
     % Atualize com o caminho da imagem do cronograma
    \caption{Diagrama de Gantt}
    \label{fig:cronograma_gantt}
\end{figure}

\vspace{1em}

\begin{figure}[H]
    \centering
     % Atualize com o caminho da segunda imagem do cronograma, se necessário
    \caption{Cronograma do Projeto}
    \label{fig:cronograma_projeto}
\end{figure}

\vspace{1em}

\begin{thebibliography}{9}
\bibitem{ref1} \href{https://arxiv.org/abs/2109.11434}{https://arxiv.org/abs/2109.11434}

\bibitem{ref2} \href{https://arxiv.org/abs/2106.11034}{https://arxiv.org/abs/2106.11034}

\bibitem{ref3} \href{https://journals.copmadrid.org/psed/art/psed2025a10}{https://journals.copmadrid.org/psed/art/psed2025a10}

\bibitem{ref4} \href{https://pubmed.ncbi.nlm.nih.gov/28494023/}{https://pubmed.ncbi.nlm.nih.gov/28494023/}

\bibitem{ref5} MakerC. \textit{DrawingBot: Open Source Plotter}. Thingiverse, 2016. Disponível em: \url{https://www.thingiverse.com/thing:2348062}.

\bibitem{ref6} Conrado, A. \textit{Controle de Máquinas CNC com GRBL}. Revista de Engenharia, 2017.

\bibitem{ref7} Handson Technology. \textit{CNC Shield V3 Documentation}. 2021. Disponível em: \url{https://www.handsontec.com}.

\end{thebibliography}

\end{document}

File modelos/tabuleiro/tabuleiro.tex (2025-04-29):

\documentclass{article}
\usepackage{tikz}
\usepackage[paperwidth=21cm, paperheight=29.7cm, top=4.85cm, bottom=4.85cm, left=0.5cm, right=0.5cm]{geometry}

\pagestyle{empty} % remove numeração de página

\setlength{\parindent}{0pt} % remove indentação
\setlength{\parskip}{0pt}   % remove espaçamento entre parágrafos

\begin{document}
\vspace*{-4.85cm} % remove espaço que empurra pra segunda página

\begin{center}
\begin{tikzpicture}
  \def\squareSize{5} % em centímetros

  \foreach \row in {0,1,2,3} {
    \foreach \col in {0,1,2,3} {
      %\pgfmathparse{mod(\row+\col,2) == 0 ? "brown!50!yellow" : "green!50!black"}
	  %\pgfmathparse{mod(\row+\col,2) == 0 ? "cyan!30!white" : "blue!70!black"}
	  %\pgfmathparse{mod(\row+\col,2) == 0 ? "olive!30!yellow" : "olive!80!black"}
	  %\pgfmathparse{mod(\row+\col,2) == 0 ? "orange!40!white" : "brown!80!red"}
	  %\pgfmathparse{mod(\row+\col,2) == 0 ? "gray!20!cyan" : "blue!80!gray"}
	  %\pgfmathparse{mod(\row+\col,2) == 0 ? "red!80!yellow" : "cyan!70!blue"}
	  %\pgfmathparse{mod(\row+\col,2) == 0 ? "orange!80!yellow" : "purple!70!black"}
	  %\pgfmathparse{mod(\row+\col,2) == 0 ? "lime!80!green" : "magenta!70!purple"}
	  \pgfmathparse{mod(\row+\col,2) == 0 ? "cyan!40!white" : "pink!80!red"}
      \edef\colorname{\pgfmathresult}
      \fill[\colorname] (\col*\squareSize, \row*\squareSize) rectangle ++(\squareSize, \squareSize);
    }
  }

  \draw[line width=1pt] (0,0) rectangle (20,20);
\end{tikzpicture}
\end{center}

\end{document}

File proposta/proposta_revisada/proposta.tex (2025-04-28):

\documentclass[a4paper,12pt]{article}  
\usepackage[utf8]{inputenc}           
\usepackage[T1]{fontenc}              
\usepackage{lmodern}                  
\usepackage{xcolor}                   
\usepackage{graphicx}                 
\usepackage{hyperref}                 
\usepackage{amsmath}                  
\usepackage{geometry}                 
\usepackage{titling}                  
\usepackage{float}                    
\usepackage{titlesec}                 
\usepackage{fancyhdr}                 
\usepackage[table]{xcolor}
\usepackage{booktabs}
\usepackage{tabularx}
\usepackage[portuguese]{babel}        
\usepackage{multirow}
\usepackage{array}

\newcolumntype{Y}{>{\raggedright\arraybackslash}p{8cm}}
\definecolor{marco}{RGB}{230, 245, 230}

% Configuração da geometria da página  
\geometry{top=2cm, bottom=2cm, left=3cm, right=3cm}  

% Configuração do hyperref  
\hypersetup{  
    colorlinks=true,  
    linkcolor=blue,  
    urlcolor=blue  
}  

% Configuração do cabeçalho e rodapé  
\pagestyle{fancy}  
\fancyhf{}  
\fancyhead[L]{Universidade Tecnológica Federal do Paraná}  
\fancyhead[R]{Oficina de Integração 1 - 2025/1}  
\fancyfoot[C]{\thepage}  
\renewcommand{\headrulewidth}{0.4pt}  
\renewcommand{\footrulewidth}{0.4pt}  

% Customização dos títulos das seções  
\titleformat{\section}  
  {\normalfont\Large\bfseries\color{black}}{\thesection}{1em}{}  
\titleformat{\subsection}  
  {\normalfont\large\bfseries\color{black}}{\thesubsection}{1em}{}  

\date{\today}  

\begin{document}  

\vspace{1em}  
\begin{center}  
    \Large\textbf{Autochess}  
\end{center}  

\vspace{1em}  

% Autores e contatos  
\begin{center}  
    \textbf{Fernando Frare Vieira} \\
	Engenharia de Computação UTFPR-CT - \textit{Turma S72}\\
    \href{mailto:fernandofrarevieira@alunos.utfpr.edu.br}{fernandofrarevieira@alunos.utfpr.edu.br} \\  
    +55 41 99900-6940 \\[1.5em]  
    \textbf{Gabriel Affonso Borges Caballero} \\ 
	Engenharia de Computação UTFPR-CT - \textit{Turma S71}\\
    \href{mailto:gabrielaffonso@alunos.utfpr.edu.br}{gabrielaffonso@alunos.utfpr.edu.br} \\  
    +55 41 99151-3335\\[1.5em]  
    \textbf{Marco Vieira Busetti} \\ 
	Engenharia Elétrica UTFPR-CT - \textit{Turma S72}\\
    \href{mailto:marcovieirabusetti@alunos.utfpr.edu.br}{marcovieirabusetti@alunos.utfpr.edu.br} \\  
    +55 41 99798-4695  
\end{center}  

\vspace{1em}  
\begin{center}  
    \today  
\end{center}  
\vspace{2em}  

% --- SEÇÃO: INTRODUÇÃO ---  
\section{Introdução}  
O projeto "Autochess" \; foi desenvolvido com o propósito pedagógico de introduzir conceitos de Machine Learning e xadrez para crianças. Utilizando um tabuleiro de xadrez simplificado (4x4), o sistema integra componentes de Inteligência Artificial e automação para demonstrar, de forma lúdica, como o aprendizado de máquina pode ser aplicado na prática. A solução proposta conta com um módulo de Visão Computacional, que realiza a captura do tabuleiro físico, e com um sistema CNC, que executa a movimentação automatizada das peças através da comunicação entre um computador e um Arduino.  

% --- SEÇÃO: MOTIVAÇÃO ---  
\section{Motivação}  
O principal objetivo deste projeto é educar crianças sobre os fundamentos do Machine Learning, uma área de extrema relevância na atualidade, por meio de uma experiência interativa e prática$^{[1], [2]}$. Além disso, o Autochess visa estimular o desenvolvimento do raciocínio lógico e da tomada de decisão, utilizando o xadrez simplificado como ferramenta de aprendizado$^{[3], [4]}$. A integração dos componentes físicos (tabuleiro e sistema CNC) com a Inteligência Artificial oferece um ambiente dinâmico, onde o aluno interage diretamente com o jogo, consolidando os conceitos através da prática.  

% --- SEÇÃO: DESCRIÇÃO GERAL ---  
\section{Descrição Geral}  
O Autochess foi concebido para funcionar de forma integrada, utilizando um computador, uma câmera e um sistema CNC. Diferente de soluções que operam apenas por meio de interfaces gráficas, o jogo é realizado de modo físico: a criança posiciona as peças no tabuleiro real e o sistema, por meio da captura de imagem, interpreta a configuração atual e, em conjunto com a Inteligência Artificial, toma a decisão sobre o movimento. Posteriormente, o sistema CNC, controlado via comunicação serial com o Arduino, efetua a movimentação física das peças. Essa abordagem garante uma experiência completa e interativa, unindo teoria e prática.  

A integração, como apresentada na Figura 1, é realizada através de comunicação serial direta entre os módulos de Visão Computacional, Inteligência Artificial e controle CNC. O sistema CNC é baseado em um manipulador cartesiano com três graus de liberdade (eixos X, Y e Z), utilizando motores de passo Nema 17 em configuração CoreXY para movimentação precisa no plano horizontal$^{[6]}$, e um servo motor SG90 para controle vertical do eletroímã responsável pela movimentação das peças.  

% --- FIGURA: TABULEIRO ---  

\begin{figure}[H]  
    \centering  
       
    \caption{Diagrama de Blocos do Sistema Minichess}  
    \label{fig:diagrama}  
\end{figure}  

\begin{figure}[H]  
    \centering  
       
    \caption{Tabuleiro do Minichess 4x4}  
    \label{fig:modelo_cnc}  
\end{figure}  

\vspace{1em}  

% --- SEÇÃO: DESCRIÇÃO DO SOFTWARE ---  
\section{Descrição do Software}  
O software deste projeto é responsável por:  
\begin{itemize}  
    \item Implementar a lógica do jogo e a Inteligência Artificial com Machine Learning, utilizando o algoritmo \textbf{Q-learning} (aprendizado por reforço) para tomada de decisão. O agente aprende a otimizar suas jogadas através de um processo iterativo, onde cada ação é associada a um valor que representa a recompensa esperada em longo prazo. O algoritmo equilibra novas jogadas e jogadas anteriores, ajustando-se dinamicamente conforme interage com o jogador. A função de recompensa é definida para priorizar vitórias, evitar derrotas e incentivar movimentos estratégicos no tabuleiro 4x4.  

    \item Capturar e processar imagens do tabuleiro físico utilizando a biblioteca OpenCV. As técnicas incluem detecção de cores, filtragem de bordas e comparação de contornos para identificar a posição das peças. A imagem é recortada para isolar o tabuleiro e evitar interferências externas.  

    \item Gerenciar a comunicação direta entre o computador e o Arduino via protocolo serial, utilizando a biblioteca PySerial para envio de comandos em G-Code. O fluxo é coordenado por um script único que integra a visão computacional, a IA e o controle do CNC, garantindo sincronização entre a decisão da jogada e a movimentação física das peças.  
\end{itemize}  

% --- SEÇÃO: DESCRIÇÃO DO HARDWARE ---  
\section{Descrição do Hardware}  
Para a realização do jogo físico, o sistema conta com os seguintes componentes de hardware:  
\begin{itemize}  
    \item \textbf{Computador com Câmera:} Utilizado para capturar imagens do tabuleiro (resolução 1920x1080) e processar as informações necessárias para a tomada de decisão. A câmera é fixada em uma estrutura de suporte 3D impressa, posicionada verticalmente para garantir visibilidade total do tabuleiro.  
    \item \textbf{Arduino UNO com CNC Shield V3:} Responsável por controlar os motores de passo (Nema 17) e o servo motor SG90. A CNC Shield utiliza drivers A4988 e um relé para acionamento do eletroímã de 12V.  
    \item \textbf{Sistema CNC CoreXY:} Composto por dois motores de passo para movimento no plano XY, seguindo o arranjo CoreXY. O eixo Z é controlado por um servo motor, responsável por abaixar e levantar o eletroímã.  
    \item \textbf{Fonte de Alimentação:} Duas fontes de 12V 5A são utilizadas: uma para os motores de passo e ventoinhas de refrigeração, e outra exclusiva para o eletroímã.  
	\item \textbf{Placa Universal:} Uma Placa Universal será utilizada para a soldagem de componentes eletrônicos auxiliares para a execução do projeto, tais como atuadores e sensores.
\end{itemize}  

% --- FIGURA: MODELO CNC ---  
\begin{figure}[H]  
    \centering  
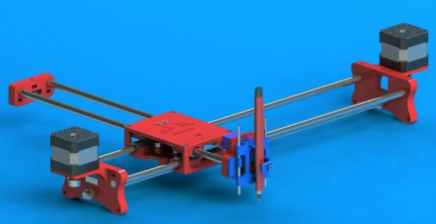
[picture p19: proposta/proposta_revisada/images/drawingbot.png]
       
    \caption{Referência do sistema CNC para movimentação física $^{[5]}$}  
    \label{fig:modelo_cnc}  
\end{figure}  

% --- SEÇÃO: LISTA DE COMPONENTES ---  
\section{Lista de Componentes}  
\begin{itemize}  
    \item \textbf{Software:}  
    \begin{itemize}  
        \item Python 3.8+ (com bibliotecas OpenCV, NumPy e PySerial)  
        \item Firmware GRBL (para interpretação de G-Code no Arduino)  
    \end{itemize}  
    \item \textbf{Hardware:}  
    \begin{itemize}  
        \item Computador com câmera USB Full HD  
        \item Arduino UNO + CNC Shield V3 + Drivers A4988  
        \item 2x Motores de Passo Nema 17 + Correias GT2  
        \item Servo Motor SG90 + Eletroímã 12V  
        \item Fonte de Alimentação 12V 5A (2 unidades)  
        \item Estrutura em MDF cortada a laser + Suportes 3D impressos  
		\item Relé
		\item Placa Universal + sensores e atuadores.
    \end{itemize}  
\end{itemize}  

% --- SEÇÃO: INTEGRAÇÃO ---  
\section{Integração entre Software e Hardware}  
A comunicação entre os módulos é realizada através de um fluxo sequencial unificado:  
\begin{enumerate}  
    \item \textbf{Visão Computacional:} Captura e processamento da imagem do tabuleiro utilizando OpenCV, gerando uma matriz 4x4 que representa o estado atual do jogo.  
    \item \textbf{Inteligência Artificial:} Processamento da matriz pelo algoritmo Q-learning para determinação da melhor jogada, com base em recompensas e aprendizado iterativo.  
    \item \textbf{Controle CNC:} Conversão das coordenadas da jogada em comandos G-Code e envio imediato ao Arduino via comunicação serial, acionando os motores e o eletroímã para movimentação das peças.  
\end{enumerate}  

% --- SEÇÃO: CRONOGRAMA ---  
\section{Cronograma}  

\begin{table}[H]
\centering
\caption{Cronograma}
\label{tab:cronograma}
\renewcommand{\arraystretch}{1.5}
\begin{tabularx}{\textwidth}{Yccc}
\toprule
\rowcolor{marco}
\textbf{Tarefa} & \textbf{Início} & \textbf{Final} & \textbf{Entrega} \\
\midrule

% Marco 1
\rowcolor{marco}
\multicolumn{4}{l}{\textbf{Marco 1}} \\
Elaboração do software com a lógica minichess rodando no computador & 07/04/2025 & 21/04/2025 & - \\
Implementação do algoritmo de Machine Learning & 14/04/2025 & 28/04/2025 & - \\
Fazer os modelos 3D das peças de xadrez planificadas & 14/04/2025 & 28/04/2025 & - \\
Fazer projeto elétrico & 14/04/2025 & 05/05/2025 & - \\
Construção Tabuleiro 4x4 & 14/04/2025 & 05/05/2025 & - \\
Realizar modelo 3D da estrutura física & 14/04/2025 & 28/04/2025 & - \\
MARCO 1 & - & - & 12/05/2025 \\

% Marco 2
\rowcolor{marco}
\multicolumn{4}{l}{\textbf{Marco 2}} \\
Impressão 3D dos objetos & 05/05/2025 & 19/05/2025 & - \\
Implementação do algoritmo de reconhecimento das peças & 28/04/2025 & 12/05/2025 & - \\
Montagem da CNC e de suas peças & 14/04/2025 & 19/05/2025 & - \\
Instalação de suporte para webcam & 05/05/2025 & 19/05/2025 & - \\
Soldagem dos componentes eletrônicos na Placa Universal & 05/05/2025 & 19/05/2025 & - \\
MARCO 2 & - & - & 26/05/2025 \\

% Marco 3
\rowcolor{marco}
\multicolumn{4}{l}{\textbf{Marco 3}} \\
Instalação do servomotor + eletroimã (eixo Z) & 19/05/2025 & 02/06/2025 & - \\
Calibração do passo da CNC & 12/05/2025 & 02/06/2025 & - \\
Comunicação serial computador - Arduino com CNC & 19/05/2025 & 02/06/2025 & - \\
Programar os scripts para os comandos GCODE & 19/05/2025 & 02/06/2025 & - \\
MARCO 3 & - & - & 09/06/2025 \\

\bottomrule
\end{tabularx}

\end{table}

\vspace{1em}  

\begin{figure}[H]  
    \centering  
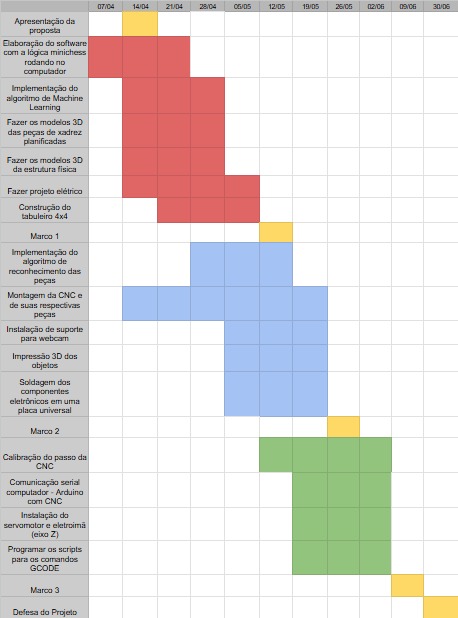
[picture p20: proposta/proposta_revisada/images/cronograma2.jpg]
       
    \caption{Diagrama de Gantt}  
    \label{fig:cronograma_projeto}  
\end{figure}  

\vspace{1em}  

% --- REFERÊNCIAS ---  
\begin{thebibliography}{9}  
\bibitem{ref1} \href{https://arxiv.org/abs/2109.11434}{https://arxiv.org/abs/2109.11434}  
\bibitem{ref2} \href{https://arxiv.org/abs/2106.11034}{https://arxiv.org/abs/2106.11034}  
\bibitem{ref3} \href{https://journals.copmadrid.org/psed/art/psed2025a10}{https://journals.copmadrid.org/psed/art/psed2025a10}  
\bibitem{ref4} \href{https://pubmed.ncbi.nlm.nih.gov/28494023/}{https://pubmed.ncbi.nlm.nih.gov/28494023/}  
\bibitem{ref5} MakerC. \textit{DrawingBot: Open Source Plotter}. Thingiverse, 2016. Disponível em: \url{https://www.thingiverse.com/thing:1517211}.  
\bibitem{ref6} \url{https://ieeexplore.ieee.org/document/10179542}
\bibitem{ref7} Conrado, A. \textit{Controle de Máquinas CNC com GRBL}. Revista de Engenharia, 2017.  
\bibitem{ref8} Handson Technology. \textit{CNC Shield V3 Documentation}. 2021. Disponível em: \url{https://www.handsontec.com}.  
\end{thebibliography}  

\end{document}

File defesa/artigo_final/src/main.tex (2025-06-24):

%===============================================================================
\documentclass[a4paper]{ifacconf}
\usepackage{graphicx,amsmath,url}      % include this line if your document contains figures
\usepackage{float}
\usepackage{url}
\usepackage[numbers]{natbib}  % Para citações numéricas (sem colchetes extras)
\bibliographystyle{plainnat}  % Ou "ifacconf", "ieeetr", "unsrt"
%===============================================================================

% ===============================================================
% Choose the language of the manuscript.
\def\portugues{1} 
% ===============================================================

\ifx\portugues\undefined
\def\portugues{0}
\fi

\if\portugues0
   \usepackage[english]{babel}
\else
   \usepackage[spanish,brazil,english]{babel}
\fi

\usepackage[T1]{fontenc}
\usepackage[utf8]{inputenc}
\usepackage{ae}
\if\portugues1
 \newtheorem{teorema}[thm]{{\em Teorema}}{ }
 \newtheorem{lema}[thm]{{\em Lema}}{ }
 \newtheorem{corolario}[thm]{{\em Corolário}}{ }
 \newenvironment{prova}{{\bf Prova.}}{ }
\fi

\begin{document}

\if\portugues1

% =====================================================================
% =====================================================================
% USE THIS PART IF THE TEXT IS IN PORTUGUES OR SPANISH
% =====================================================================
% If the manuscript is in Spanish, please change the texts adequately.
% =====================================================================
% 
\selectlanguage{brazil}
	
\begin{frontmatter}

\title{Autochess: Sistema Físico Interativo de Xadrez com Machine Learning Educacional} 
% Title, preferably not more than 10 words.

%\thanks[footnoteinfo]{Este trabalho foi desenvolvido como projeto da disciplina Oficina de Integração 1 (ELEX20) do curso de Engenharia de Computação da UTFPR.}

\author{\centering\parbox{7cm}{\centering
Fernando Frare Vieira*\\
Gabriel Affonso Borges Caballero**\\
Marco Vieira Busetti***}}

\address{*Engenharia de Computação, Universidade Tecnológica Federal do Paraná, (e-mail: fernandofrarevieira@alunos.utfpr.edu.br)\\
**Engenharia de Computação, Universidade Tecnológica Federal do Paraná, (e-mail: gabrielaffonso@alunos.utfpr.edu.br)\\
***Engenharia Elétrica, Universidade Tecnológica Federal do Paraná, (e-mail: marcovieirabusetti@alunos.utfpr.edu.br)}

\selectlanguage{english}
\renewcommand{\abstractname}{{\bf Abstract:~}}
\begin{abstract}              
This paper presents a physical and interactive chess system designed to teach artificial intelligence concepts to children. The project uses a reduced 4×4 chessboard where users play against a Q-Learning-based AI that adapts its strategy throughout the game. Piece movement is handled by a CoreXY manipulator equipped with Nema 17 stepper motors and an SG90 servo motor, controlled by an Arduino UNO running GRBL-Servo firmware. Board state recognition is performed through computer vision using the SIFT (Scale-Invariant Feature Transform) algorithm.
\vskip 1mm% 
\selectlanguage{brazil}
{\noindent \bf Resumo}: Este trabalho apresenta um sistema físico e interativo de xadrez, desenvolvido com o objetivo de ensinar conceitos de inteligência artificial para crianças. O projeto utiliza um tabuleiro reduzido 4x4, no qual usuários jogam contra uma IA baseada em Q-Learning que se adapta durante o jogo. A movimentação física utiliza um manipulador CoreXY com motores Nema 17 e um servo SG90, controlados por Arduino UNO com firmware GRBL-servo. A detecção da configuração das peças no tabuleiro é feita por meio de visão computacional, utilizando o algoritmo SIFT.
\end{abstract}

\selectlanguage{english}
\begin{keyword}
Machine Learning; Computer Vision; Automation; Chess; Technology Education; Q-Learning; SIFT; CoreXY.

\vskip 1mm% não altere esse espaçamento
\selectlanguage{brazil}
{\noindent\it Palavras-chaves:} Machine Learning; Visão Computacional; Automação; Xadrez; Educação Tecnológica; Q-Learning; SIFT; CoreXY.
\end{keyword}

\selectlanguage{brazil}

\end{frontmatter}
\else
% ===============================================================
% ===============================================================
% USE THIS PART IF THE TEXT IS IN ENGLISH
% ===============================================================
% ===============================================================
% 

\begin{frontmatter}

\title{Style for SBA Conferences \& Symposia: Use Title Case for
  Paper Title\thanksref{footnoteinfo}} 
% Title, preferably not more than 10 words.

\thanks[footnoteinfo]{Sponsor and financial support acknowledgment
goes here. Paper titles should be written in uppercase and lowercase
letters, not all uppercase.}

\author[First]{First A. Author} 
\author[Second]{Second B. Author, Jr.} 
\author[Third]{Third C. Author}

\address[First]{Faculdade de Engenharia Elétrica, Universidade do Triângulo, MG, (e-mail: autor1@faceg@univt.br).}
\address[Second]{Faculdade de Engenharia de Controle \& Automação, Universidade do Futuro, RJ (e-mail: autor2@feca.unifutu.rj)}
\address[Third]{Electrical Engineering Department, 
   Seoul National University, Seoul, Korea, (e-mail: author3@snu.ac.kr)}
   
\renewcommand{\abstractname}{{\bf Abstract:~}}   
   
\begin{abstract}                % Abstract of not more than 250 words.
These instructions give you guidelines for preparing papers for IFAC
technical meetings. Please use this document as a template to prepare
your manuscript. For submission guidelines, follow instructions on
paper submission system as well as the event website.
\end{abstract}

\begin{keyword}
Five to ten keywords, preferably chosen from the IFAC keyword list.
\end{keyword}

\end{frontmatter}
\fi

%===============================================================================
%===============================================================================
%===============================================================================

\section{Introdução}

\selectlanguage{brazil}

\par\noindent Na última década, a popularização de tecnologias como a inteligência artificial e a automação têm gerado avanços e transformações em diversas áreas do conhecimento, incluindo a educação~\cite{tedre2021teaching}. Em paralelo, cresce a necessidade de que as novas gerações compreendam esses conceitos, pois essas tecnologias estão cada vez mais presentes no cotidiano. Porém, apesar dessa crescente demanda, ainda existem diversos desafios na introdução desses temas complexos de forma acessível para públicos mais jovens, especialmente crianças em idade escolar.

\par\noindent Uma das dificuldades mais comuns é encontrar formas de ensinar os fundamentos da inteligência artificial de maneira prática e compreensível. Há uma carência de métodos educacionais que demonstrem o funcionamento de uma IA de forma interativa e visível, permitindo que as crianças observem concretamente como ocorre o processo de aprendizado e tomada de decisão computacional.

\par\noindent O xadrez, historicamente utilizado como benchmark para avaliar sistemas de inteligência artificial~\cite{ensmenger2012chess}, oferece um contexto ideal para demonstração desses conceitos. Desde o desenvolvimento do Deep Blue da IBM até sistemas mais recentes como o AlphaZero, o xadrez tem servido como plataforma para avanços significativos em IA. Contudo, a complexidade do xadrez tradicional (com aproximadamente $10^{120}$ possíveis jogos) torna impraticável sua implementação em sistemas educacionais com recursos limitados.

\par\noindent Diante desse cenário, este trabalho propõe uma solução lúdica e educativa utilizando uma variante simplificada do xadrez (Minichess 4×4) como meio para introduzir conceitos de inteligência artificial, visão computacional e automação. O projeto também visa estimular o raciocínio lógico e a curiosidade tecnológica através da interação direta com um sistema físico autônomo~\cite{novak2021touching}.

\par\noindent Este artigo apresenta o desenvolvimento do projeto Autochess, que consiste em um tabuleiro de xadrez físico 4×4 que integra módulos de visão computacional baseada em SIFT, inteligência artificial utilizando Q-Learning e um sistema CNC controlado por Arduino com firmware GRBL-servo. O objetivo é demonstrar como o aprendizado de máquina pode ser implementado de forma prática no processo educativo, incentivando o interesse por tecnologia desde os estágios iniciais da formação escolar.

\section{Trabalhos relacionados}

\par\noindent A intersecção entre jogos, inteligência artificial e educação tem sido explorada por diversos pesquisadores. Silver et al.~\cite{silver2016alphago} demonstraram o potencial do aprendizado por reforço no contexto de jogos através do AlphaGo, que utilizou técnicas de aprendizado profundo combinadas com busca em árvore Monte Carlo. Embora aplicado ao jogo de Go, os princípios fundamentais são relevantes para sistemas educacionais baseados em jogos.

\par\noindent No contexto específico de variantes simplificadas de xadrez, Gardner~\cite{gardner1981minichess} formalizou diversas modalidades de Minichess, incluindo a variante Silverman 4×4 utilizada neste trabalho. Essa simplificação permite análise completa do espaço de estados e facilita a implementação de algoritmos de aprendizado, tornando-se ideal para fins educacionais.

\par\noindent Sistemas físicos para ensino de robótica e automação têm ganhado destaque na literatura. Benitti~\cite{benitti2012exploring} realizou uma revisão sistemática sobre o uso de robótica educacional, destacando os benefícios de sistemas físicos interativos no desenvolvimento de habilidades STEM (\textit{Science, Technology, Engineering and Mathematics}). O presente trabalho contribui para essa área ao integrar conceitos de IA, visão computacional e automação em um único sistema educacional.

\par\noindent Especificamente sobre sistemas de xadrez automatizados, diversos projetos têm sido desenvolvidos utilizando diferentes abordagens tecnológicas. Contudo, a maioria foca em aspectos puramente técnicos, sem considerar o potencial educacional ou a demonstração visual do processo de aprendizado da IA, lacuna que este trabalho pretende preencher.

\section{Materiais e Orçamento}

O desenvolvimento do sistema Autochess priorizou a utilização de componentes acessíveis e amplamente disponíveis no mercado nacional e internacional, visando demonstrar a viabilidade econômica do projeto para aplicações educacionais. A Tabela~\ref{tab:orcamento} apresenta a relação completa dos materiais utilizados e seus respectivos custos.

\begin{table}[H]
\centering
\begin{tabular}{|l|c|c|}
  \hline
  \textbf{Item} & \textbf{Qtd.} & \textbf{Preço (R\$)} \\
  \hline
  Arduino Uno & 2 & 40,00 \\
  Shield CNC V3 + Drivers & 1 & 15,00 \\
  Eletroimã & 1 & 6,00 \\
  Motor Nema 17 & 2 & 40,00 \\
  Servo motor SG90 & 1 & 5,00 \\
  Placa universal & 1 & 12,00 \\
  Patolas & 2 & 30,00 \\
  Fonte de alimentação & 2 & 50,00 \\
  Webcam Full HD & 1 & 50,00 \\
  Impressão 3D & - & 100,00 \\
  Base MDF & - & 40,00 \\
  Outros (fios, conectores, etc) & - & 30,00 \\
  \hline
  \textbf{Total} & & \textbf{418,00} \\
  \hline
\end{tabular}
\caption{Relação de materiais e custos do projeto Autochess.}
\label{tab:orcamento}
\end{table}

O projeto foi desenvolvido com um orçamento acessível, utilizando componentes facilmente encontrados no mercado nacional e internacional, o que resulta em um custo-benefício adequado para fins educacionais.

\section{Metodologia}
\par\noindent Esta seção descreve os procedimentos adotados para o desenvolvimento do projeto Autochess. Serão apresentados a visão geral do sistema, os aspectos mecânicos envolvidos na construção da estrutura, os componentes de hardware utilizados, e o software desenvolvido para os módulos de IA e visão computacional.

\subsection{Visão geral}
\par\noindent O Autochess é um sistema interativo que integra diferentes módulos tecnológicos para permitir a realização de partidas de xadrez em um ambiente físico com controle automatizado. A arquitetura do projeto foi planejada para que a interação entre o usuário e o sistema ocorra de forma contínua, envolvendo visão computacional, inteligência artificial e execução dos movimentos através de um sistema CNC. 

\par\noindent O ciclo de funcionamento do sistema inicia-se com a realização de um movimento pelo jogador humano no tabuleiro físico. Após concluir sua jogada, o usuário pressiona um botão indicando que o sistema pode proceder à análise. Então uma câmera realiza a captura de uma imagem do tabuleiro, a qual é processada por algoritmos de Visão Computacional para identificar a nova configuração das peças. A posição atual do jogo é convertida em uma representação matricial, que é enviada como entrada para o módulo de Inteligência Artificial. A IA processa esta informação e determina o próximo movimento da máquina, retornando as coordenadas da jogada a ser realizada. Por fim, o comando correspondente é transmitido via comunicação serial para o sistema CNC, que executa automaticamente a movimentação física da peça no tabuleiro, completando o ciclo de interação. A Figura~\ref{fig:diagrama} ilustra o fluxo geral de funcionamento do sistema.

\begin{figure}[H]
\begin{center}
    % The printed column width is 8.4 cm.
\caption{Diagrama geral do funcionamento do projeto.}
\par\small\textit{Fonte: Autoria própria.}
\label{fig:diagrama}
\end{center}
\end{figure}

\subsection{Hardware Mecânico}

\par\noindent A parte mecânica do projeto consiste em um sistema de movimentação das peças de xadrez baseado em arquitetura CoreXY, além de estruturas de suporte para os demais elementos do sistema, como a câmera utilizada para visão computacional. A escolha da arquitetura CoreXY foi motivada por suas vantagens em termos de eficiência no uso do espaço, precisão de movimentação e velocidade de operação.

\par\noindent Durante a fase de desenvolvimento, toda a estrutura foi previamente modelada em software de modelagem tridimensional, permitindo a visualização detalhada da montagem antes da construção física. O modelo 3D completo está apresentado na Figura~\ref{fig:modelo3d}.

\begin{figure}[H]
\begin{center}
    % The printed column width is 8.4 cm.
\caption{Modelo 3D do sistema completo.}
\par\small\textit{Fonte: Autoria própria.}
\label{fig:modelo3d}
\end{center}
\end{figure}

\par\noindent A estrutura principal do CoreXY foi baseada no projeto open-source DrawingBot da MakerC~\cite{makerc2016drawingbot}, disponibilizado através da plataforma Thingiverse. As peças estruturais foram fabricadas através de impressão 3D em material PLA, oferecendo leveza e facilidade de produção.
As peças de xadrez impressas em 3D também se mostraram adequadas para comportar uma moeda de ferro magnetizado, utilizado para a atração via eletroimã das peças.
Os arquivos originais foram adaptados para comportar os componentes específicos deste projeto, incluindo o suporte da câmera e o mecanismo de fixação do eletroímã.

\par\noindent Todos os componentes foram montados sobre uma base de MDF cortada a laser, oferecendo uma superfície de apoio para a fixação dos motores e suportes. O uso do MDF contribui tanto para a redução de custos quanto para a leveza do conjunto, facilitando o transporte e manuseio do sistema. A Figura~\ref{fig:basemdf} apresenta o design da base de MDF utilizada no projeto.

\begin{figure}[H]
\begin{center}
    % The printed column width is 8.4 cm.
\caption{Design da base de MDF cortada a laser.}
\par\small\textit{Fonte: Autoria própria.}
\label{fig:basemdf}
\end{center}
\end{figure}

\par\noindent A movimentação nos eixos X e Y é realizada por dois motores de passo Nema 17, com torque de 4,2 kg·cm e precisão de 1,8° por passo. A transmissão do movimento é feita através de uma correia dentada GT2 e quatro polias sincronizadas de 20 dentes, dispostas segundo o padrão cruzado característico do sistema CoreXY. Esta configuração permite que ambos os motores contribuam para o movimento em qualquer direção, resultando em maior velocidade e precisão.

\par\noindent O movimento do eixo Z foi implementado utilizando um servo motor SG90, que aciona um mecanismo de elevação e descida do eletroímã. O eletroímã utilizado possui força de atração de aproximadamente 2,5 kg a 12V, suficiente para manipular as peças de xadrez. A estrutura CoreXY implementada está ilustrada na Figura~\ref{fig:corexy}.

\begin{figure}[H]
\begin{center}
    % The printed column width is 8.4 cm.
\caption{Estrutura cruzada CoreXY utilizada no projeto.}
\par\small\textit{Fonte: Tested 3D Prints \cite{corexyfig}.}
\label{fig:corexy}
\end{center}
\end{figure}

\par\noindent Para a captura de imagens, foi desenvolvido um suporte específico para câmera, modelado e impresso em 3D, que posiciona a webcam Full HD perpendicularmente sobre o tabuleiro a uma altura adequada para visualização completa da área de jogo, conforme mostrado na Figura~\ref{fig:camera}.

\begin{figure}[H]
\begin{center}
    % The printed column width is 8.4 cm.
\caption{Suporte para câmera desenvolvido para o projeto.}
\par\small\textit{Fonte: Autoria própria.}
\label{fig:camera}
\end{center}
\end{figure}

\par\noindent As peças de xadrez também foram especialmente projetadas para o projeto, incluindo moedas de ferro magnetizado em suas bases para permitir a manipulação magnética. A Figura~\ref{fig:rainha} apresenta o modelo da rainha e sua base, a qual possui uma abertura para inserção de uma moeda de ferro magnetizada.

\begin{figure}[H]
\centering

\hspace{0.02\columnwidth}

\caption{Modelo 3D da peça rainha com sua base.}
\par\small\textit{Fonte: Autoria própria.}
\label{fig:rainha}
\end{figure}

\subsection{Hardware Eletrônico}
\par\noindent A implementação do hardware eletrônico envolveu a integração de diversos componentes, responsáveis pela comunicação entre os módulos de software e o controle do sistema CNC. Foi utilizado um computador que atua como o cérebro do sistema, executando a lógica principal da inteligência artificial e coordenando os módulos periféricos. Ele se comunica com dois Arduinos por meio de conexões seriais via USB, delegando o controle físico da movimentação CNC e da interface com o usuário. 

\par\noindent O projeto elétrico do sistema de movimentação da CNC está apresentada na Figura~\ref{fig:projeto_eletrico}.

\begin{figure}[H]
\begin{center}
    % The printed column width is 8.4 cm.
\caption{Diagrama do projeto elétrico do sistema.}
\par\small\textit{Fonte: Autoria própria.}
\label{fig:projeto_eletrico}
\end{center}
\end{figure}

\par\noindent Para o controle da movimentação CNC, foi utilizado um Arduino UNO executando o firmware GRBL-servo, uma versão modificada do projeto open-source GRBL disponibilizado por Robottini~\cite{robottini2020grbl} no Github. O GRBL-servo é capaz de interpretar comandos G-code padrão para movimentação dos motores de passo, com a extensão adicional de controle de servo motor. Durante a implementação, o firmware foi modificado para ajustar os ângulos específicos de abertura e fechamento do servo motor, permitindo o controle preciso das operações de captura e soltura das peças.

\par\noindent O driver utilizado para os motores de passo é o shield CNC V3, que incorpora drivers A4988 para cada motor. Este shield oferece microstepping configurável (até 1/16 de passo), permitindo movimentação suave e precisa. A alimentação dos motores é fornecida por uma fonte externa de 12V/5A, isolada do circuito de controle do Arduino.

\par\noindent O segundo Arduino UNO foi integrado ao sistema para gerenciar a interface com o usuário através de três botões físicos. O primeiro botão deve ser pressionado pelo jogador após concluir sua jogada, sinalizando ao sistema para iniciar a captura e processamento da imagem do tabuleiro. O segundo botão permite ao usuário indicar o término da partida, ativando a rotina de finalização. O terceiro botão tem a função de reinicializar a inteligência artificial, apagando todo o conhecimento acumulado (tabela Q) e retornando a IA ao estado inicial de aprendizado.

\par\noindent A decisão de utilizar um segundo Arduino dedicado aos botões foi tomada para evitar sobrecarga no Arduino da CNC, que já opera com a CNC Shield V3 e o firmware GRBL-servo, exigente em termos de temporização e controle; integrar os botões e um LED RGB ao mesmo microcontrolador poderia causar conflitos de hardware e dificultar a manutenção do sistema.

\subsection{Software}
\par\noindent O desenvolvimento do software para o projeto consiste na implementação de dois módulos principais: a Inteligência Artificial responsável por decidir os movimentos da máquina e a Visão Computacional encarregada da captura e interpretação da posição das peças no tabuleiro. Ambos os módulos foram desenvolvidos em Python, utilizando bibliotecas especializadas para cada função. A integração entre a visão computacional, a inteligência artificial e o sistema de movimentação foi realizada por meio de um programa desenvolvido em Python, denominado \textit{Core}. 

\subsubsection{4.4.1 Inteligência Artificial:}

\par\noindent Para reduzir a complexidade computacional e viabilizar o treinamento da IA em tempo hábil, optou-se por utilizar uma variante simplificada do xadrez tradicional, conhecida como Silverman 4×4. Essa modalidade, pertencente à família de jogos Minichess, é jogada em um tabuleiro 4×4 e conta com um conjunto reduzido de peças: rei, rainha, torres  e peões para cada jogador, conforme mostrado na Figura~\ref{fig:minichess4x4}.

\begin{figure}[H]
\begin{center}
    % The printed column width is 8.4 cm.
\caption{Configuração inicial do tabuleiro Silverman 4×4.}
\par\small\textit{Fonte: Wikipedia \cite{wikipedia_minichess}}
\label{fig:minichess4x4}
\end{center}
\end{figure}

\par\noindent A configuração inicial do tabuleiro Silverman 4×4 posiciona as peças brancas na primeira fileira (rainha em a1, rei em b1, torre em c1 e peão em d1) e na segunda fileira (peões em a2, b2, c2, d2). As peças pretas ocupam posições simétricas nas fileiras 3 e 4. Esta configuração reduzida mantém a essência estratégica do xadrez enquanto permite análise computacional viável.

\par\noindent A IA foi desenvolvida utilizando a técnica de Aprendizado por Reforço, através do algoritmo Q-Learning, modelado como um Processo de Decisão de Markov (MDP)~\cite{watkins1992q}.

\begin{itemize}
\item \textbf{Estados (S):} Cada estado representa uma configuração única do tabuleiro, codificada como uma matriz 4×4 onde cada célula contém a identificação da peça presente;
\item \textbf{Ações (A):} Conjunto de todos os movimentos legais possíveis em um dado estado, respeitando as regras de movimento de cada tipo de peça;
\item \textbf{Função de Recompensa (R):} Definida de forma simples como +1 para vitórias, 0 para empates e -1 para derrotas;
\item \textbf{Política de Ação:} Implementada através de estratégia $\varepsilon$-gulosa para equilibrar exploração e exploração.
\end{itemize}

\par\noindent A equação (1) representa a atualização do Q-Learning~\cite{sutton2018reinforcement}:

\begin{equation}
    Q(s,a) \leftarrow Q(s,a) + \alpha \left[ r + \gamma \max_{a'} Q(s',a') - Q(s,a) \right]
\end{equation}

\par\noindent onde $\alpha = 0.5$ é a taxa de aprendizado, $\gamma = 0.9$ é o fator de desconto, $r$ é a recompensa recebida, $s'$ é o novo estado e $a'$ representa as ações possíveis no novo estado.

Os valores de $\alpha$ e $\gamma$ foram escolhidos empiricamente após testes preliminares, visando garantir uma taxa de aprendizado moderada e boa retenção de conhecimento a longo prazo.

\par\noindent A estratégia $\varepsilon$-gulosa~\cite{sutton2018reinforcement} foi implementada com decaimento linear, iniciando com $\varepsilon = 0.9$ (alta exploração) e decrescendo gradualmente até $\varepsilon = 0.01$ (predominante exploração), permitindo que a IA explore amplamente o espaço de estados nas fases iniciais de treinamento e posteriormente se concentre em explorar o conhecimento adquirido.

\par\noindent Para fins de validação e análise visual, foi desenvolvida uma interface gráfica utilizando a biblioteca PyGame, permitindo a simulação das partidas entre humanos e a IA, bem como partidas entre diferentes versões da IA para avaliação de desempenho. A interface implementada está ilustrada na Figura~\ref{fig:minichess}.

\begin{figure}[H]
\begin{center}
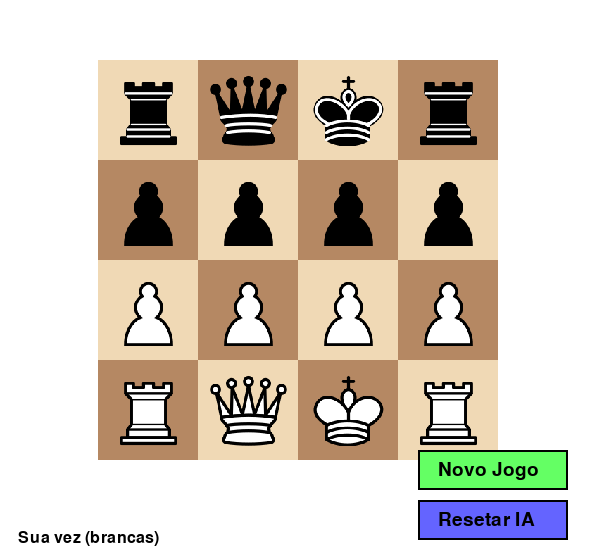
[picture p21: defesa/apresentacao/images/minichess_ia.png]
    % The printed column width is 8.4 cm.
\caption{Interface gráfica do tabuleiro Minichess 4×4 desenvolvida em PyGame.}
\par\small\textit{Fonte: Autoria própria}
\label{fig:minichess}
\end{center}
\end{figure}

\subsubsection{4.4.2 Visão Computacional:}

\par\noindent O módulo de visão computacional tem como função principal identificar automaticamente o estado atual do tabuleiro após cada jogada do usuário. Este processo é iniciado com a captura de uma imagem através de uma webcam Full HD posicionada fixamente acima do tabuleiro, oferecendo uma visão perpendicular completa da área de jogo.

\par\noindent Durante a etapa de processamento, o sistema enfrenta diversos desafios técnicos, incluindo variações na iluminação ambiente, distorções ópticas da lente da câmera, reflexos na superfície das peças e a necessidade de distinguir com alta precisão as peças brancas e pretas sob diferentes condições de luminosidade.

\par\noindent A solução adotada foi a implementação do algoritmo \textbf{SIFT (Scale-Invariant Feature Transform)}, uma técnica robusta para detecção de pontos-chave e descrição de características locais invariantes à escala, rotação e iluminação~\cite{lowe2004sift}. O SIFT foi escolhido por sua comprovada eficácia em reconhecimento de objetos em condições adversas e sua capacidade de manter consistência mesmo com variações significativas nas condições de captura.

\par\noindent O processo de reconhecimento segue as seguintes etapas:

\begin{enumerate}
\item \textbf{Pré-processamento:} A imagem capturada é convertida para escala de cinza e submetida a filtros de suavização para redução de ruído;
\item \textbf{Segmentação do tabuleiro:} Utilização de detecção de contornos e transformação de perspectiva para isolar a região de interesse (tabuleiro) e corrigir distorções angulares;
\item \textbf{Divisão em células:} O tabuleiro segmentado é dividido matematicamente em 16 células (4×4), com cada célula sendo analisada individualmente;
\item \textbf{Extração de características SIFT:} Para cada célula, são extraídos pontos-chave e descritores SIFT que caracterizam as texturas e formas presentes;
\item \textbf{Matching com banco de referências:} Os descritores extraídos são comparados com um banco de imagens de referência previamente construído, contendo exemplares de cada tipo de peça em diferentes posições e condições de iluminação;
\item \textbf{Classificação e mapeamento:} Com base na similaridade dos descritores, cada célula é classificada como vazia ou contendo uma peça específica, gerando a matriz 4×4 que representa o estado atual do tabuleiro.
\end{enumerate}

\par\noindent O banco de referências foi construído através da captura de múltiplas imagens de cada tipo de peça sob diferentes condições de iluminação e posicionamento, totalizando aproximadamente 50 imagens de referência por tipo de peça. Este processo garante robustez no reconhecimento mesmo com variações nas condições de captura durante o uso real do sistema.

\par\noindent As Figuras~\ref{fig:exemplo1_cv}, \ref{fig:exemplo2_cv} e \ref{fig:exemplo3_cv} demonstram exemplos práticos da aplicação do algoritmo SIFT para reconhecimento das peças em diferentes condições, evidenciando a robustez da solução adotada.

\par\noindent Note que do lado direito da imagem está o resultado do tratamento realizado pelo SIFT. Temos as peças brancas denotadas como círculos brancos e peças pretas denotadas como círculos pretos. A inicial de cada peça se encontra no centro de cada círculo, onde \textit{P} denota \textit{Pawn} (Peão), \textit{R} denota \textit{Rook} (Torre), \textit{Q} denota \textit{Queen} (Rainha) e \textit{K} denota \textit{King} (Rei).

\begin{figure}[H]
\begin{center}
    % The printed column width is 8.4 cm.
\caption{Exemplo 1 da aplicação do algoritmo SIFT para reconhecimento de peças.}
\par\small\textit{Fonte: Autoria própria}
\label{fig:exemplo1_cv}
\end{center}
\end{figure}

\begin{figure}[H]
\begin{center}
    % The printed column width is 8.4 cm.
\caption{Exemplo 2 da aplicação do algoritmo SIFT para reconhecimento de peças.}
\par\small\textit{Fonte: Autoria própria}
\label{fig:exemplo2_cv}
\end{center}
\end{figure}

\begin{figure}[H]
\begin{center}
    % The printed column width is 8.4 cm.
\caption{Exemplo 3 da aplicação do algoritmo SIFT para reconhecimento de peças.}
\par\small\textit{Fonte: Autoria própria}
\label{fig:exemplo3_cv}
\end{center}
\end{figure}

\subsubsection{4.4.3 Core:} 

O \textit{Core} do sistema consiste no script principal em Python, que roda em um computador, atuando como o orquestrador central, ao integrar os outros módulos do projeto. A lógica da partida é gerenciada pela classe Minichess, que mantém o estado atual do tabuleiro com uma matriz 4x4. Essa matriz interna serve como a "verdade" do sistema antes de cada jogada humana. O ciclo do script espera por uma entrada "0", "1" ou "2". Essas entradas servem para, respectivamente, confirmar uma jogada, começar um novo jogo e reiniciar a IA.

Ao receber o sinal, o \textit{Core} aciona o módulo de CV para capturar e processar a imagem, que retorna uma nova matriz do estado do tabuleiro. Nesta etapa, um tratamento de erros é executado: o script verifica se a nova configuração é resultado de um movimento válido a partir da matriz interna. Se não for válido, uma nova foto é tirada e processada. Isso ocorre até que haja um movimento válido, garantindo a integridade do jogo. Com a jogada humana validada, o \textit{Core} a infere comparando a matriz antiga com a nova para obter as coordenadas de origem e destino. 

Por fim, essa jogada é submetida à IA para determinar a resposta da máquina, e o movimento resultante é traduzido em comandos G-code e enviado ao controlador CNC para a execução física, completando o ciclo.

\section{Resultados e Discussão}

\subsection{Avaliação da Inteligência Artificial}

\par\noindent Para avaliar a eficácia do algoritmo Q-Learning implementado, foi desenvolvida uma metodologia sistemática de testes baseada em múltiplas sessões de treinamento. O protocolo experimental consistiu em 30 sessões distintas, cada uma com 20 partidas sequenciais, totalizando 600 partidas analisadas. A cada nova sessão, a inteligência artificial era reinicializada, garantindo a independência estatística dos dados coletados.

\par\noindent As métricas de avaliação adotadas foram:
\begin{itemize}
\item \textbf{Média de jogadas por partida:} Indicador da duração das partidas, refletindo a capacidade da IA de dificultar vitórias imediatas de partidas;
\item \textbf{Número de \textit{blunders} (erros graves):} Quantificação de erros críticos que resultam em perda imediata de material ou posição;
\item \textbf{Saldo de material:} Relação de peças ganhas e peças perdidas pela IA;
\item \textbf{Porcentagem de jogadas seguras:} Proporção de movimentos que não colocam peças próprias em risco desnecessário.
\end{itemize}

\par\noindent O aumento na média de jogadas por partida, como visto na Figura \ref{fig:jogadas_niveis}, sugere que a IA está indo além da simples prevenção de derrotas imediatas. Ela aprende a construir sequências de jogadas mais complexas, prolongando a partida e indicando um entendimento de estratégia posicional, o que torna o jogo mais desafiador para o oponente humano.

\begin{figure}[H]
\begin{center}
    % The printed column width is 8.4 cm.
\caption{Evolução da média de jogadas por partida ao longo do treinamento.}
\par\small\textit{Fonte: Autoria própria}
\label{fig:jogadas_niveis}
\end{center}
\end{figure}

\par\noindent A análise da porcentagem de jogadas seguras, apresentada na Figura~\ref{fig:seguras_niveis}, revela melhoria significativa na capacidade da IA de evitar movimentos arriscados. Observa-se crescimento de aproximadamente 60\% na taxa de jogadas seguras entre a primeira e a vigésima partida, indicando aprendizado efetivo de princípios básicos de segurança posicional.

\begin{figure}[H]
\begin{center}
    % The printed column width is 8.4 cm.
\caption{Evolução da porcentagem de jogadas seguras durante o treinamento.}
\par\small\textit{Fonte: Autoria própria}
\label{fig:seguras_niveis}
\end{center}
\end{figure}

\par\noindent O saldo de material, mostrado na Figura~\ref{fig:material_niveis}, demonstra a evolução da capacidade da IA de preservar suas peças e capturar peças adversárias de forma estratégica. A tendência crescente evidencia o aprendizado de conceitos fundamentais de valor das peças e trocas vantajosas.

\begin{figure}[H]
\begin{center}
    % The printed column width is 8.4 cm.
\caption{Evolução do saldo de material ao longo das partidas.}
\par\small\textit{Fonte: Autoria própria}
\label{fig:material_niveis}
\end{center}
\end{figure}

\par\noindent A redução no número de \textit{blunders}, apresentada na Figura~\ref{fig:blunders_niveis}, confirma a diminuição de erros críticos conforme o treinamento progride. A diferença no número de blunders entre as primeiras e últimas partidas de cada sessão demonstra a eficácia do algoritmo Q-Learning em aprender a evitar movimentos manifestamente prejudiciais.

\begin{figure}[H]
\begin{center}
    % The printed column width is 8.4 cm.
\caption{Redução no número de \textit{blunders} durante o treinamento.}
\par\small\textit{Fonte: Autoria própria}
\label{fig:blunders_niveis}
\end{center}
\end{figure}

\par\noindent Os gráficos de desempenho ilustram uma narrativa de aprendizado coesa e progressiva. A evolução da IA começa com uma acentuada redução de \textit{blunders}, Figura \ref{fig:blunders_niveis}, estabelecendo uma base defensiva crucial. Essa estratégia é então refinada com o aumento de jogadas seguras, Figura \ref{fig:jogadas_niveis}, indicando uma transição de uma simples prevenção de erros para um planejamento proativo. A consequência direta dessa evolução é a melhoria no saldo de material, Figura \ref{fig:material_niveis}, o que confirma que o algoritmo Q-Learning traduz eficazmente a experiência de jogo em uma vantagem tangível e mensurável no tabuleiro.

\subsection{Avaliação do Sistema Integrado}

\par\noindent A precisão do sistema CNC foi avaliada através de medições da acurácia de posicionamento, apresentando desvio médio inferior a 2mm em relação às posições alvo. Esta precisão mostrou-se adequada para a manipulação das peças de xadrez, não interferindo na jogabilidade.

\par\noindent O módulo de visão computacional demonstrou taxa de acerto de elevada na identificação correta das peças, com os erros concentrados em situações de iluminação extremamente baixa ou alta reflexividade das peças. O tempo médio de processamento de uma imagem foi de 3,2 segundos, concentrando apenas um alto tempo de processamento em tabuleiros cheios.

\section{Limitações e Trabalhos Futuros}

\par\noindent Durante o desenvolvimento e testes do sistema, foram identificadas algumas limitações que representam oportunidades para melhorias futuras:

\par\noindent \textbf{Limitações do Hardware:} A utilização de dois microcontroladores Arduino UNO aumentou o acoplamento com o computador. A base de MDF apresentou pequenos desníveis que ocasionalmente afetaram a precisão de posicionamento. Diferenças na velocidade de resposta entre os motores de passo geraram pequenas assimetrias na movimentação.

\par\noindent \textbf{Limitações do Software:} O tempo de processamento da visão computacional aumenta significativamente em tabuleiros com muitas peças, limitando a fluidez da interação. O algoritmo Q-Learning, embora eficaz para a variante 4×4, apresenta limitações de escalabilidade para versões mais complexas do jogo.

\par\noindent \textbf{Trabalhos Futuros:} Propõe-se a unificação do controle em um único microcontrolador para realizar todas as tarefas do projeto, simplificando a arquitetura do sistema. A implementação de algoritmos de visão computacional mais eficientes, possivelmente baseados em aprendizado profundo, poderia melhorar a velocidade e precisão do reconhecimento. O desenvolvimento de versões expandidas do jogo, incluindo tabuleiros 6×6 ou 8×8, permitiria observar mais claramente a evolução da IA, uma vez que a variante do xadrez 4x4 é fechada. A integração de elementos de gamificação e sistema de pontuação poderia aumentar o engajamento educacional.

\section{Conclusões}

\par\noindent Este trabalho apresentou o desenvolvimento bem-sucedido de um sistema integrado para ensino de conceitos de inteligência artificial através de um jogo de xadrez físico automatizado. O projeto Autochess demonstrou a viabilidade de combinar técnicas de aprendizado de máquina, visão computacional e automação em uma plataforma educacional acessível e interativa.

\par\noindent Os resultados obtidos confirmaram a eficácia do algoritmo Q-Learning na aprendizagem de estratégias básicas de xadrez, com melhoria consistente de desempenho ao longo de múltiplas sessões de treinamento. A implementação do algoritmo SIFT para reconhecimento de peças se mostrou robusta e confiável, apesar do alto tempo de processamento prejudicar a fluídez do jogo.

\par\noindent O custo total de R\$ 418,00 torna o sistema economicamente viável para aplicações educacionais. Apesar disso, a escolha da base de MDF, embora de baixo custo, resultou em um leve envergamento ao longo do tempo, criando desníveis na superfície que exigiram ajustes manuais com pesos para garantir a precisão do braço mecânico.

\par\noindent A arquitetura CoreXY adotada para o sistema CNC proporcionou precisão adequada para a manipulação das peças, enquanto a estrutura modular do projeto facilitou a manutenção e possíveis expansões futuras.

\par\noindent Contudo, é fundamental reconhecer que a arquitetura atual do projeto apresenta uma limitação significativa: o sistema não é \textit{plug and play}. A dependência de um computador executando o código Python para os módulos de Inteligência Artificial e Visão Computacional impede que o dispositivo funcione de maneira autônoma. Essa característica representa uma barreira prática para sua aplicação direta em ambientes educacionais sem a devida preparação técnica, e aponta para a clara necessidade de, em trabalhos futuros, embarcar essa inteligência em um hardware integrado, como um Raspberry Pi, para criar uma solução verdadeiramente independente.

\par\noindent O trabalho contribui para a área de robótica educacional ao integrar múltiplas disciplinas em um único sistema coeso, oferecendo uma ferramenta prática para demonstração de conceitos abstratos de IA. A metodologia desenvolvida pode ser aplicada a outros jogos e contextos educacionais, expandindo as possibilidades de ensino através de sistemas físicos interativos.

\par\noindent Futuras versões do sistema poderão incorporar as melhorias sugeridas, expandindo suas capacidades educacionais e técnicas. A base sólida estabelecida neste projeto oferece fundamentos para desenvolvimentos mais avançados na intersecção entre educação, inteligência artificial e automação.

\section*{Agradecimentos}
\par\noindent Os autores agradecem à disciplina de Oficina de Integração 1 pela oportunidade de desenvolvimento deste projeto, aos professores Juliano Mourão Vieira, Eduardo Nunes dos Santos e Ronnier Frates Rohrich (DAELN) pela orientação, e ao Professor Bogdan Tomoyuki Nassu (DAINF) pelo apoio no desenvolvimento da Visão Computacional. Agradecimentos especiais à Maker Mate pela disponibilização da estrutura física e equipamentos necessários para a construção do sistema.

\begin{thebibliography}{99}

\bibitem{tedre2021teaching}
Tedre, M., Toivonen, T., Kahila, J., Vartiainen, H., Valtonen, T., Jormanainen, I., \& Pears, A. (2021). Teaching machine learning in K-12 computing education: Potential and pitfalls. \textit{ACM Transactions on Computing Education (TOCE)}, 21(3), 1-26.

\bibitem{ensmenger2012chess}
Ensmenger, N. (2012). Is chess the drosophila of artificial intelligence? A social history of an algorithm. \textit{Social Studies of Science}, 42(1), 5-30.

\bibitem{novak2021touching}
Novak, M., \& Schwan, S. (2021). Does touching real objects affect learning?. \textit{Educational Psychology Review}, 33(2), 637-665.

\bibitem{silver2016alphago}
Silver, D., Huang, A., Maddison, C. J., Guez, A., Sifre, L., Van Den Driessche, G., ... \& Hassabis, D. (2016). Mastering the game of Go with deep neural networks and tree search. \textit{Nature}, 529(7587), 484-489.

\bibitem{gardner1981minichess}
Gardner, M. (1981). \textit{Minichess variants}. \textit{Mathematical Games}, Scientific American, 244(1), 18-22.

\bibitem{benitti2012exploring}
Benitti, F. B. V. (2012). Exploring the educational potential of robotics in schools: A systematic review. \textit{Computers \& Education}, 58(3), 978-988.

\bibitem{corexyfig}
Tested 3D Prints. \textit{Homework Writing Machine – Arduino based CoreXY Plotter}. Disponível em: \url{https://test3dprints.com/arduino/homework-writing-machine/}. Acesso em: 22 jun. 2025.

\bibitem{makerc2016drawingbot}
MakerC. (2016). \textit{DrawingBot - CoreXY Drawing Robot}. Disponível em: https://www.thingiverse.com/thing:1517211. Acesso em: 10 dez. 2024.

\bibitem{wikipedia_minichess}
Wikipedia. \textit{Minichess}. Disponível em: \url{https://en.wikipedia.org/wiki/Minichess}. Acesso em: 22 jun. 2025.

\bibitem{robottini2020grbl}
Robottini. (2020). \textit{GRBL-Servo: CNC Controller with Servo Support}. Disponível em: https://github.com/robottini/grbl-servo. Acesso em: 15 dez. 2024.

\bibitem{watkins1992q}
Watkins, C. J., \& Dayan, P. (1992). Q-learning. \textit{Machine Learning}, 8(3-4), 279-292

\bibitem{sutton2018reinforcement}
Sutton, R. S., \& Barto, A. G. (2018). \textit{Reinforcement learning: An introduction}. MIT press.

\bibitem{lowe2004sift}
Lowe, D. G. (2004). Distinctive image features from scale-invariant keypoints. \textit{International Journal of Computer Vision}, 60(2), 91-110.

\end{thebibliography}

\end{document}

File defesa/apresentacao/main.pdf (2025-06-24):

### Autochess

Fernando F. Vieira
Gabriel A. B. Caballero
Marco V. Busetti

Oficina de Integração 1 (ELEX20) Engenharia de Computação - UTFPR

24 de junho de 2025

### Roteiro da Apresentação

1 | Introdução
2 | Hardware
3 | Mecânica
4 | Software
5 | Resultados

### Introdução

1 | Introdução
2 | Hardware
3 | Mecânica
4 | Software
5 | Resultados

### Escopo e Objetivos

O projeto Autochess foi desenvolvido com propósito pedagógico: introduzir conceitos de Machine Learning e xadrez para crianças. Utiliza um tabuleiro 4x4 simplificado, composto por:
Módulo de Inteligência Artificial.
Módulo de Visão Computacional.
Sistema CNC.

### Diagrama de blocos

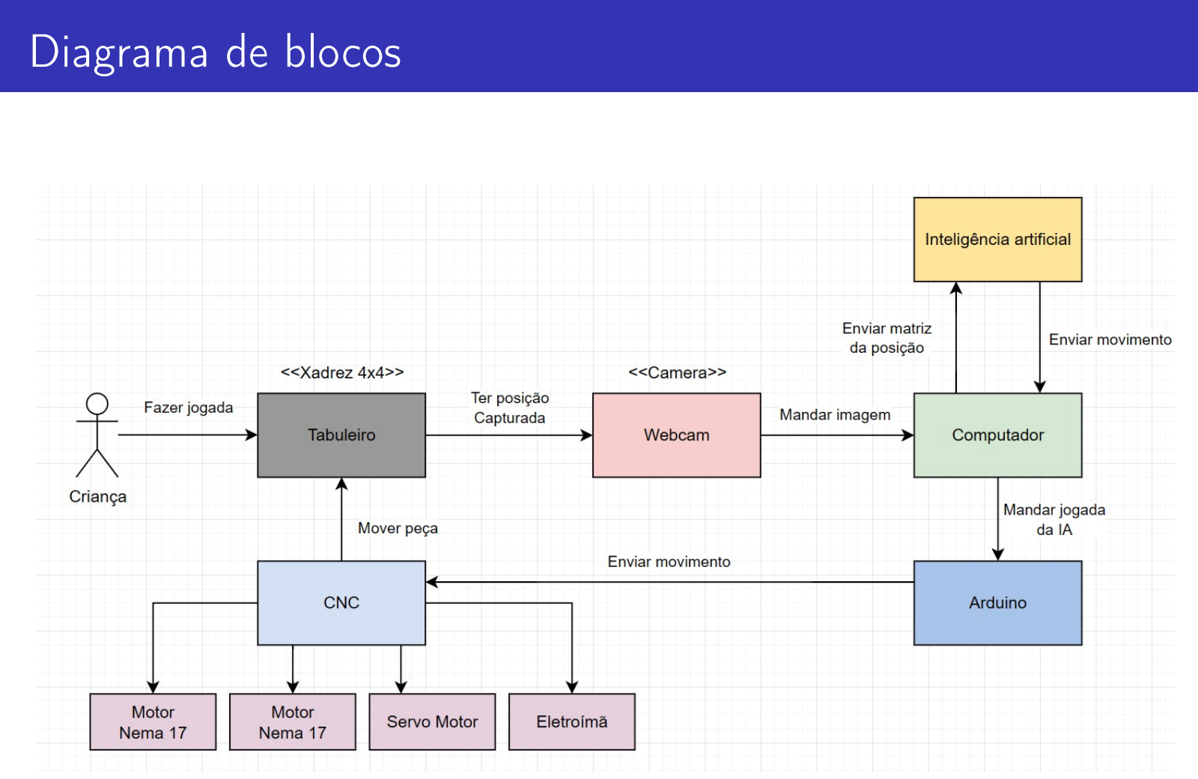
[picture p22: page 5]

### Idealização do projeto

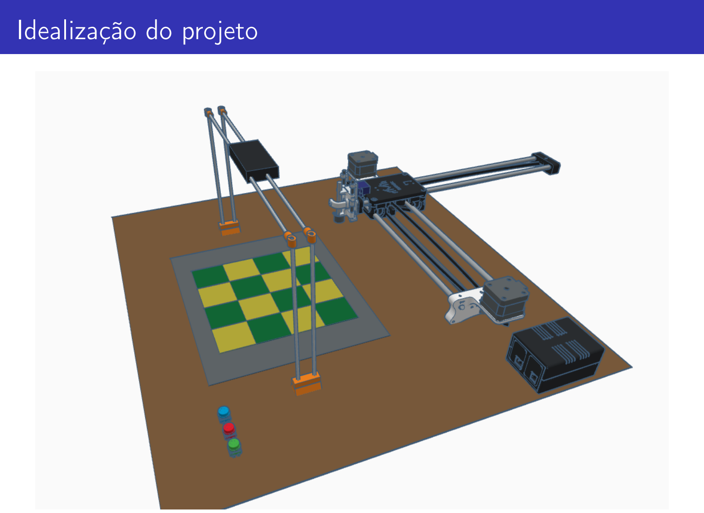
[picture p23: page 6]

### Materiais e Orçamento

Item | Quantidade | Preço (R$)
Arduino Uno | 2 | 40,00
Shield CNC V3 + Drivers | 1 | 15,00
Eletroimã | 1 | 6,00
Nema 17 | 2 | 40,00
Servo motor SG90 | 1 | 5,00
Placa universal | 1 | 12,00
Patolas | 2 | 30,00
Fonte de alimentação | 2 | 50,00
Webcam Full HD | 1 | 50,00
Impressão 3D | - | 100,00
Base MDF | - | 40,00
Outros (fios, conectores, etc) | - | 30,00
Total | | 418,00

Observação: Componentes eletrônicos adquiridos via AliExpress. (https://pt.aliexpress.com)

### Hardware

1 | Introdução
2 | Hardware
3 | Mecânica
4 | Software
5 | Resultados

### Idealização do projeto elétrico

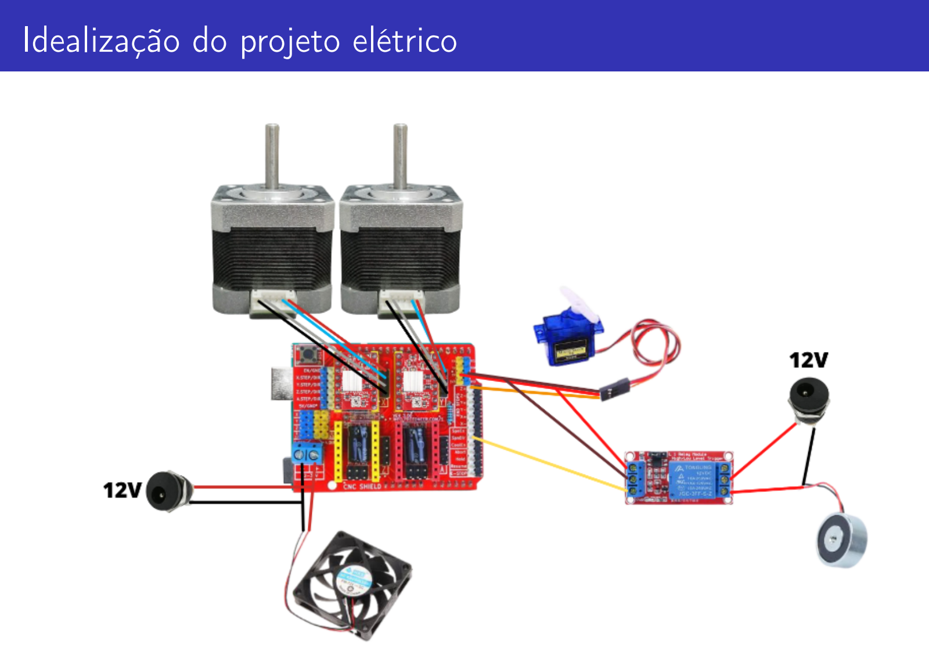
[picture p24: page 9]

Algumas modificações...

Foram utilizados 2 Arduinos UNO.
Tarefas de cada um:
Arduino 1: Controle da CNC (firmware GRBL-servo); Arduino 2: Receber input dos botões.

### Controle e Firmware

Utilizado o firmware GRBL-servo, baseado no repositório da Robottini¹
GRBL é um firmware open-source que interpreta comandos G-code para controle de CNCs.
Permitiu o controle dos motores de passo, eletroímã e servomotor com precisão.
Foram realizadas algumas modificações no código fonte do firmware para adaptar o ângulo de abertura do servomotor.

1 https://github.com/robottini/grbl-servo

### Mecânica

1 | Introdução
2 | Hardware
3 | Mecânica
4 | Software
5 | Resultados

### Estrutura CoreXY


Figura: Estrutura cruzada CoreXY

Fonte: test3dprints.com

### CoreXY - Princípio de Funcionamento

Os motores estão fixos na estrutura.
O movimento é transmitido por apenas uma correia e polias dispostas em padrão cruzado.
Os motores atuam juntos para gerar os deslocamentos nos eixos.

### Vantagens do CoreXY

Motores não se movem junto.
Alta velocidade e aceleração.
Estrutura simétrica e eficiente no uso do espaço. Redução de inércia no movimento.
Uso de apenas uma correia.

### Estrutura física do projeto

Para o suporte da CNC foi utilizado como base o projeto DrawingBot da MakerC²
Arquivos para impressão 3D disponibilizados foram utilizados.
Todos os objetos são apoiados em uma base de MDF cortada à laser. Fora a estrutura impressa 3D da CNC (já pronta), todos os outros objetos (peças de xadrez, suporte para câmera, etc.) foram modelados à parte.

2 https://www.thingiverse.com/thing:1517211

### Modelo da base do MDF

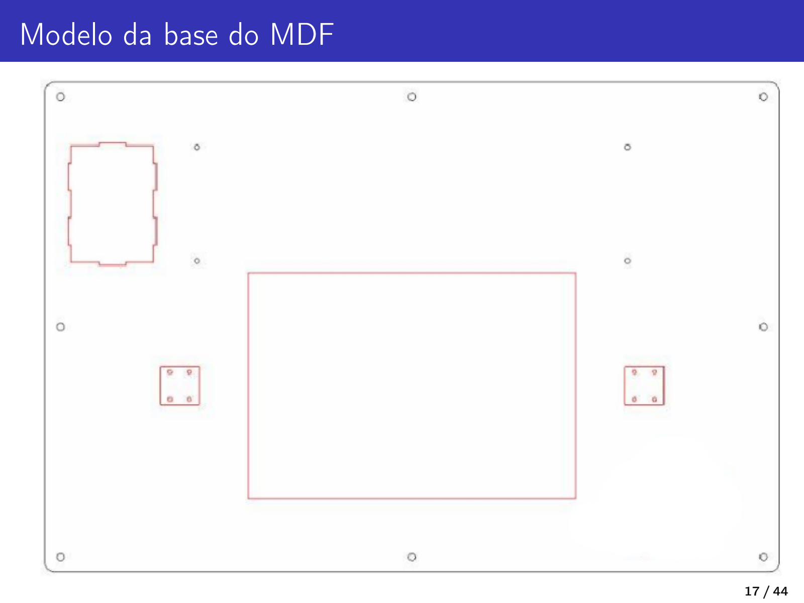
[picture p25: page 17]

### Modelos 3D - suporte para câmera


### Modelos 3D - peças do xadrez


Rainha | Base da Rainha

### Software

1 | Introdução
2 | Hardware
3 | Mecânica
4 | Software
5 | Resultados

### Visão Computacional

Para identificar o estado do jogo automaticamente, foi necessário utilizar técnicas de visão computacional sobre imagens capturadas por uma câmera fixa.

### Visão Computacional

Desafios enfrentados
Segmentação precisa da área do tabuleiro, mesmo com distorções da câmera.
Diferenciação entre peças brancas e pretas sob diferentes condições de iluminação.
Identificação das peças no tabuleiro, considerando posições variadas.

### Visão Computacional

Solução adotada
Utilizamos o SIFT (Scale-Invariant Feature Transform) para detecção de pontos-chave robustos.
Detecção de contornos das figuras das peças e extremidades do tabuleiro.
As descrições extraídas com SIFT permitiram realizar matching entre peças reais e modelos de referência.

### Implementação do SIFT - Exemplos


### Implementação do SIFT - Exemplos


### Implementação do SIFT - Exemplos


### Implementação do SIFT - Exemplos


### Minichess 4×4 – Variante Silverman

Minichess é uma família de variantes do xadrez tradicional, jogadas em tabuleiros menores.
A variante Silverman 4×4 é jogada com as seguintes peças:
Rei, torre, rainha e peões.
Útil para estudo de algoritmos, resolução de jogos e IA aplicada.

### Minichess 4×4 – Variante Silverman


Figura: Silverman 4x4

Fonte: https://en.wikipedia.org/wiki/Minichess

### IA com Q-Learning no Silverman 4×4

Modelamos o jogo como um Processo de Decisão de Markov (MDP):
Estados (S): todas as possíveis configurações do tabuleiro.
Ações (A): todos os movimentos legais em um dado estado. Recompensa (R): +1 para vitória, 0 para empate, -1 para derrota. Utilizamos Q-Learning, um algoritmo off-policy de aprendizagem por reforço:

Q(s, a) ← Q(s, a) + α

r + γ max
a

′

Q(s

′
, a

′
) − Q(s, a)

Estratégia ε-gulosa para equilibrar exploration & exploitation:

Escolhe melhor ação com probabilidade 1 − ε, aleatória com ε

### Parâmetros do Q-Learning e ε-gulosa

Taxa de aprendizado α:
→ Valor utilizado: α = 0.5.
Fator de desconto γ:
→ Valor utilizado: γ = 0.9.
Taxa de exploração ε (estratégia ε-gulosa):
→ Inicialmente alta (ex: 0.9), decresce ao longo do treinamento para valores baixos (ex: 0.1 ou 0.01).

### Q-Learning

1 Inicializar Q(s, a) arbitrariamente 2 for cada episódio (partida) do
3 | Inicializar estado s
4 | while jogo não terminou do
5 | Com probabilidade ε, escolher ação aleatória a
6 | Caso contrário, escolher a = arg maxa ′ Q(s, a ′ )
7 | Executar ação a, observar recompensa r e novo
| estado s ′
8 | Atualizar:
9 | Q(s, a) ← Q(s, a) + α [r + γ maxa ′ Q(s ′ , a ′ ) − Q(s, a)]
10 | s ← s

′
11 end
12 end

### Metodologia de Avaliação da IA

Número de sessões: 30 sessões distintas, com reinicialização da IA ao início de cada sessão.
Partidas por sessão: 20 partidas sequenciais por sessão, totalizando 600 partidas analisadas.
Métricas utilizadas:
1 | Média de jogadas por partida;
2 | Número de blunders;
3 | Saldo de material;
4 | Jogadas seguras (%).
Média de todas sessões de uma determinada partida.

### Q-Learning - Levantamento estatístico sob os resultados


### Q-Learning - Levantamento estatístico sob os resultados


### Q-Learning - Levantamento estatístico sob os resultados


### Q-Learning - Levantamento estatístico sob os resultados


## Core

Um programa denominado Core ficou encarregado da integração entre visão computacional, IA e o movimento da CNC.
É o cérebro do projeto.

### Resultados

1 | Introdução
2 | Hardware
3 | Mecânica
4 | Software
5 | Resultados

### Resultados - decisões que funcionaram bem

Hardware:
Comunicação serial bem sucedida: firmare GRBL servo funcionou como deveria;
Mecânica:
Estrutura do braço CNC forte e confiável (desvio médio inferior a 2mm);
Peças de xadrez 3D respondendo perfeitamente às atrações magnéticas. Software:
Machine learning apresentou evolução com o decorrer das partidas; Visão Computacional confiável em diversas condições de luz e posições de peças.

### Resultados - problemas a serem melhorados

Hardware:
Utilização de dois Arduinos para comunicação serial; Mecânica:
Base MDF causando desníveis;
Um motor de passo "mais lento"que o outro.
Software:
Visão Computacional tomando muito tempo para processamento de tabuleiro cheio (média de 3,2 segundos).

### Conclusão dos Resultados

O sistema funcionou bem como uma ferramenta prática e didática para apresentar aprendizado de máquina a um público infantil.
A experiência mostrou que a escolha das ferramentas e abordagens foi acertada:
O uso do GRBL com Arduinos se provou uma solução estável e prática; A estrutura mecânica funcionou como esperado, e as peças responderam bem ao controle magnético;
A IA conseguiu aprender com poucas partidas, o que validou a proposta de demonstrar aprendizado de máquina de forma acessível e dinâmica; A visão computacional se manteve confiável mesmo com variações de luz e disposição das peças.

### Próximos Passos

Melhorar a estrutura da base para evitar desníveis;
Unificar o controle em um único microcontrolador;
Otimizar a visão computacional para situações com muitas peças.

### Agradecimentos

# Muito obrigado pela atenção!

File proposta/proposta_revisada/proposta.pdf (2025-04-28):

Universidade Tecnológica Federal do Paraná Oficina de Integração 1 - 2025/1

## Autochess

Fernando Frare Vieira
Engenharia de Computação UTFPR-CT - Turma S72 fernandofrarevieira@alunos.utfpr.edu.br
+55 41 99900-6940

Gabriel Affonso Borges Caballero Engenharia de Computação UTFPR-CT - Turma S71 gabrielaffonso@alunos.utfpr.edu.br +55 41 99151-3335

Marco Vieira Busetti
Engenharia Elétrica UTFPR-CT - Turma S72 marcovieirabusetti@alunos.utfpr.edu.br +55 41 99798-4695

28 de abril de 2025

## 1 Introdução

O projeto "Autochess" foi desenvolvido com o propósito pedagógico de introduzir conceitos de Machine Learning e xadrez para crianças. Utilizando um tabuleiro de xadrez simplificado (4x4), o sistema integra componentes de Inteligência Artificial e automação para demonstrar, de forma lúdica, como o aprendizado de máquina pode ser aplicado na prática. A solução proposta conta com um módulo de Visão Computacional, que realiza a captura do tabuleiro físico, e com um sistema CNC, que executa a movimentação automatizada das peças através da comunicação entre um computador e um Arduino.

## 2 Motivação

O principal objetivo deste projeto é educar crianças sobre os fundamentos do Machine Learning, uma área de extrema relevância na atualidade, por meio de uma experiência interativa e prática[1],[2]. Além disso, o Autochess visa estimular o desenvolvimento do raciocínio lógico e da tomada de decisão, utilizando o xadrez simplificado como ferramenta de aprendizado[3],[4]. A integração dos componentes físicos (tabuleiro e sistema CNC) com a Inteligência Artificial oferece um ambiente dinâmico, onde o aluno interage diretamente com o jogo, consolidando os conceitos através da prática.

## 3 Descrição Geral

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


Figura 1: Diagrama de Blocos do Sistema Minichess


Figura 2: Tabuleiro do Minichess 4x4

## 4 Descrição do Software

O software deste projeto é responsável por:

- Implementar a lógica do jogo e a Inteligência Artificial com Machine Learning, utilizando o algoritmo Q-learning (aprendizado por reforço) para tomada de decisão. O agente aprende a otimizar suas jogadas através de um processo iterativo, onde cada ação é associada a um valor que representa a recompensa esperada em longo prazo. O algoritmo equilibra novas jogadas e jogadas anteriores, ajustando-se dinamicamente conforme interage com o jogador. A função de recompensa é definida para priorizar vitórias, evitar derrotas e incentivar movimentos estratégicos no tabuleiro 4x4.
- Capturar e processar imagens do tabuleiro físico utilizando a biblioteca OpenCV. As técnicas incluem detecção de cores, filtragem de bordas e comparação de contornos para identificar a posição das peças. A imagem é recortada para isolar o tabuleiro e evitar interferências externas.
- Gerenciar a comunicação direta entre o computador e o Arduino via protocolo serial, utilizando a biblioteca PySerial para envio de comandos em G-Code. O fluxo é coordenado por um script único que integra a visão computacional, a IA e o controle do CNC, garantindo sincronização entre a decisão da jogada e a movimentação física das peças.

## 5 Descrição do Hardware

Para a realização do jogo físico, o sistema conta com os seguintes componentes de hardware:

- Computador com Câmera: Utilizado para capturar imagens do tabuleiro (resolução 1920x1080) e processar as informações necessárias para a tomada de decisão. A câmera é fixada em uma estrutura de suporte 3D impressa, posicionada verticalmente para garantir visibilidade total do tabuleiro.
- Arduino UNO com CNC Shield V3: Responsável por controlar os motores de passo (Nema 17) e o servo motor SG90. A CNC Shield utiliza drivers A4988 e um relé para acionamento do eletroímã de 12V.
- Sistema CNC CoreXY: Composto por dois motores de passo para movimento no plano XY, seguindo o arranjo CoreXY. O eixo Z é controlado por um servo motor, responsável por abaixar e levantar o eletroímã.
- Fonte de Alimentação: Duas fontes de 12V 5A são utilizadas: uma para os motores de passo e ventoinhas de refrigeração, e outra exclusiva para o eletroímã.
- Placa Universal: Uma Placa Universal será utilizada para a soldagem de componentes eletrônicos auxiliares para a execução do projeto, tais como atuadores e sensores.


Figura 3: Referência do sistema CNC para movimentação física [5]

## 6 Lista de Componentes

- Software:

– Python 3.8+ (com bibliotecas OpenCV, NumPy e PySerial)

– Firmware GRBL (para interpretação de G-Code no Arduino)

- Hardware:

– Computador com câmera USB Full HD

– Arduino UNO + CNC Shield V3 + Drivers A4988

– 2x Motores de Passo Nema 17 + Correias GT2

– Servo Motor SG90 + Eletroímã 12V
– Fonte de Alimentação 12V 5A (2 unidades)

– Estrutura em MDF cortada a laser + Suportes 3D impressos

– Relé

– Placa Universal + sensores e atuadores.

## 7 Integração entre Software e Hardware

A comunicação entre os módulos é realizada através de um fluxo sequencial unificado:

1. Visão Computacional: Captura e processamento da imagem do tabuleiro utilizando OpenCV, gerando uma matriz 4x4 que representa o estado atual do jogo.
2. Inteligência Artificial: Processamento da matriz pelo algoritmo Q-learning para determinação da melhor jogada, com base em recompensas e aprendizado iterativo.
3. Controle CNC: Conversão das coordenadas da jogada em comandos G-Code e envio imediato ao Arduino via comunicação serial, acionando os motores e o eletroímã para movimentação das peças.

## 8 Cronograma

Tabela 1: Cronograma

Tarefa | Início | Final | Entrega

Marco 1

Elaboração do software com a lógica
minichess rodando no computador
07/04/2025 21/04/2025 | -

Implementação do algoritmo de Machine Learning

14/04/2025 28/04/2025 | -

Fazer os modelos 3D das peças de xadrez
planificadas
14/04/2025 28/04/2025 | -
Fazer projeto elétrico | 14/04/2025 05/05/2025 | -
Construção Tabuleiro 4x4 | 14/04/2025 05/05/2025 | -
Realizar modelo 3D da estrutura física | 14/04/2025 28/04/2025 | -
MARCO 1 | - | - | 12/05/2025

Marco 2

Impressão 3D dos objetos | 05/05/2025 19/05/2025 | -

Implementação do algoritmo de
reconhecimento das peças
28/04/2025 12/05/2025 | -
Montagem da CNC e de suas peças | 14/04/2025 19/05/2025 | -
Instalação de suporte para webcam | 05/05/2025 19/05/2025 | -

Soldagem dos componentes eletrônicos na
Placa Universal
05/05/2025 19/05/2025 | -
MARCO 2 | - | - | 26/05/2025

Marco 3

Instalação do servomotor + eletroimã (eixo
Z)
19/05/2025 02/06/2025 | -
Calibração do passo da CNC | 12/05/2025 02/06/2025 | -

Comunicação serial computador - Arduino
com CNC
19/05/2025 02/06/2025 | -

Programar os scripts para os comandos
GCODE
19/05/2025 02/06/2025 | -
MARCO 3 | - | - | 09/06/2025


Figura 4: Diagrama de Gantt
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

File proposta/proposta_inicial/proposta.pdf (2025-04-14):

Universidade Tecnológica Federal do Paraná Oficina de Integração 1 - 2025/1

## Autochess

Fernando Frare Vieira
Engenharia de Computação UTFPR-CT - Turma S72 fernandofrarevieira@alunos.utfpr.edu.br
+55 41 99900-6940

Gabriel Affonso Borges Caballero Engenharia de Computação UTFPR-CT - Turma S71 gabrielaffonso@alunos.utfpr.edu.br +55 41 99151-3335

Marco Vieira Busetti
Engenharia Elétrica UTFPR-CT - Turma S72 marcovieirabusetti@alunos.utfpr.edu.br +55 41 99798-4695

14 de abril de 2025

## 1 Introdução

O projeto "Autochess" foi desenvolvido com o propósito pedagógico de introduzir conceitos de Machine Learning e xadrez para crianças. Utilizando um tabuleiro de xadrez simplificado (4x4), o sistema integra componentes de Inteligência Artificial e automação para demonstrar, de forma lúdica, como o aprendizado de máquina pode ser aplicado na prática. A solução proposta conta com um módulo de Visão Computacional, que realiza a captura do tabuleiro físico, e com um sistema CNC, que executa a movimentação automatizada das peças através da comunicação entre um computador e um Arduino.
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

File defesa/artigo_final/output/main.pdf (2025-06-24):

## Autochess: Sistema F´ısico Interativo de Xadrez com Machine Learning Educacional

Fernando Frare Vieira*
Gabriel Affonso Borges Caballero** Marco Vieira Busetti***

*Engenharia de Computa¸c˜ao, Universidade Tecnol´ogica Federal do Paran´a, (e-mail: fernandofrarevieira@alunos.utfpr.edu.br) **Engenharia de Computa¸c˜ao, Universidade Tecnol´ogica Federal do Paran´a, (e-mail: gabrielaffonso@alunos.utfpr.edu.br) ***Engenharia El´etrica, Universidade Tecnol´ogica Federal do Paran´a, (e-mail: marcovieirabusetti@alunos.utfpr.edu.br)
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

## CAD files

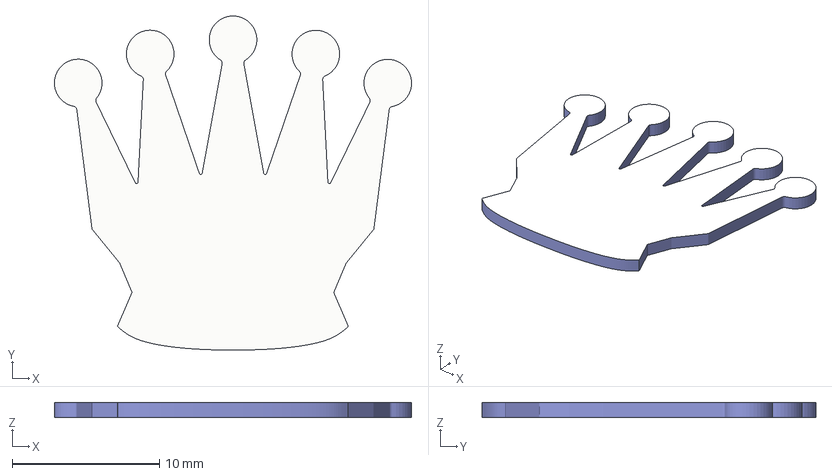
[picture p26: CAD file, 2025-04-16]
modelos/peças_xadrez_3d/Rainha.3mf
24.3 x 22.7 x 1.00 mm

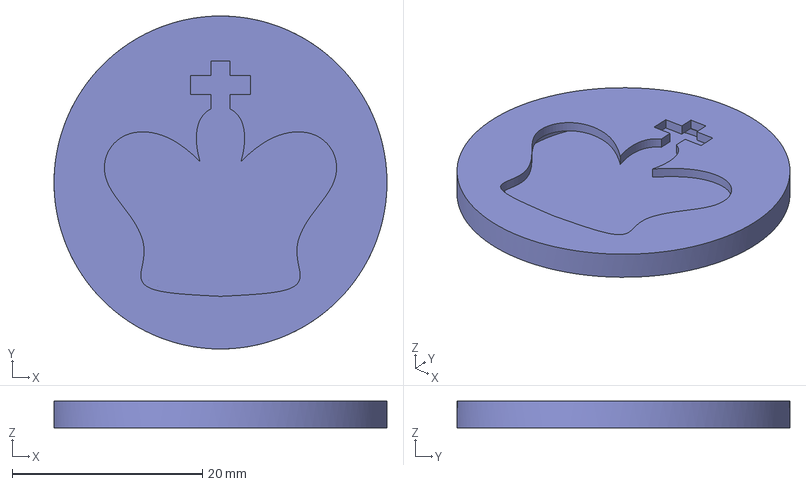
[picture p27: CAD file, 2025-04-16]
modelos/peças_xadrez_3d/Base Rei.3mf
35.0 x 35.0 x 2.80 mm

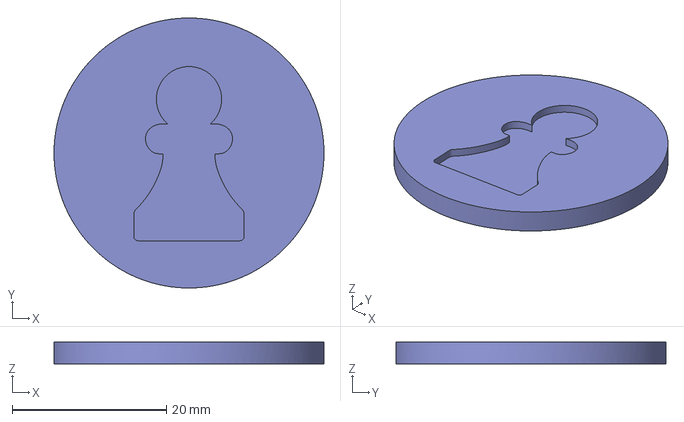
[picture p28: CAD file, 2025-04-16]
modelos/peças_xadrez_3d/Base Peão.3mf
35.0 x 35.0 x 2.80 mm

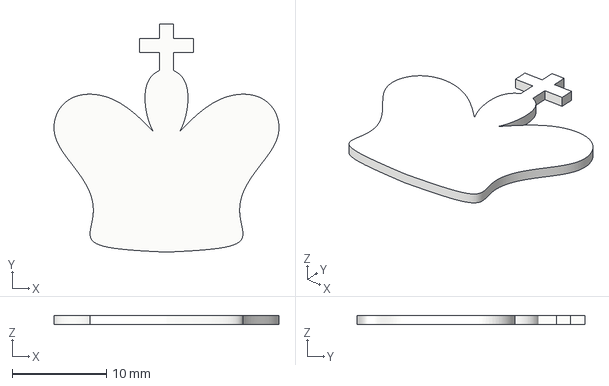
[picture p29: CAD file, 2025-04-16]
modelos/peças_xadrez_3d/Rei.3mf
23.9 x 24.2 x 1.00 mm

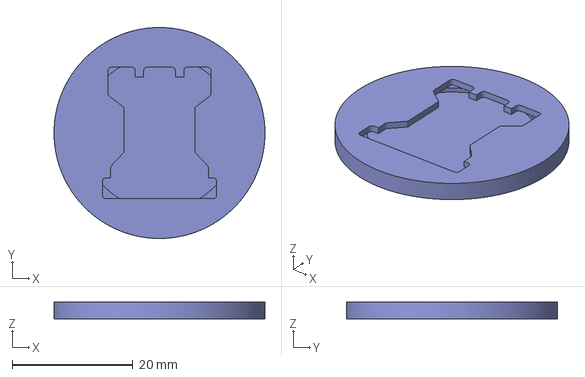
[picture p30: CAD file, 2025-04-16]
modelos/peças_xadrez_3d/Base Torre.3mf
35.0 x 35.0 x 2.80 mm

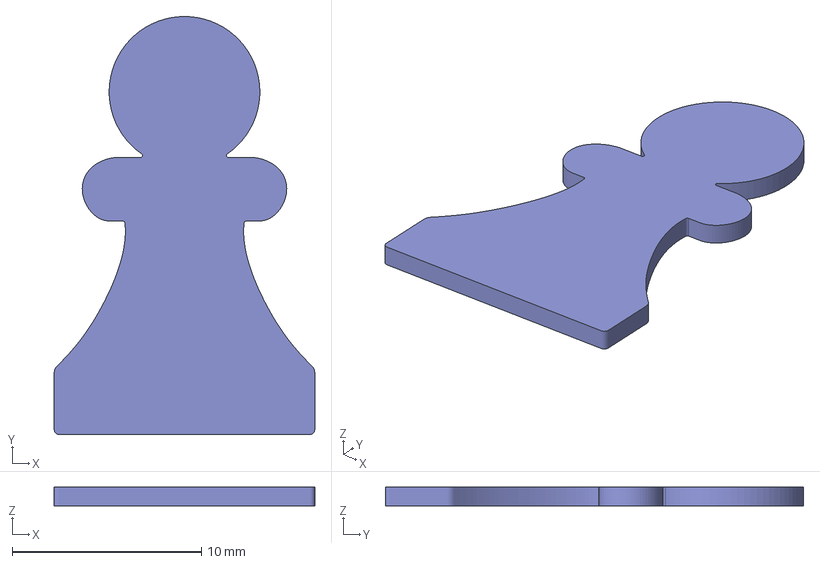
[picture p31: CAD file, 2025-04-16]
modelos/peças_xadrez_3d/Peão.3mf
13.8 x 22.1 x 1.00 mm

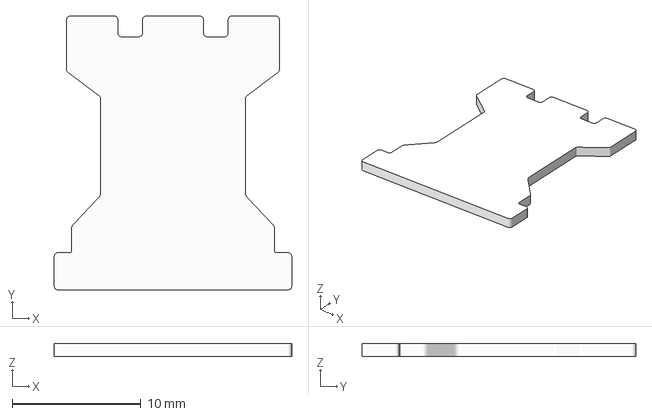
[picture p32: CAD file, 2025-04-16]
modelos/peças_xadrez_3d/Torre.3mf
18.5 x 21.3 x 1.00 mm

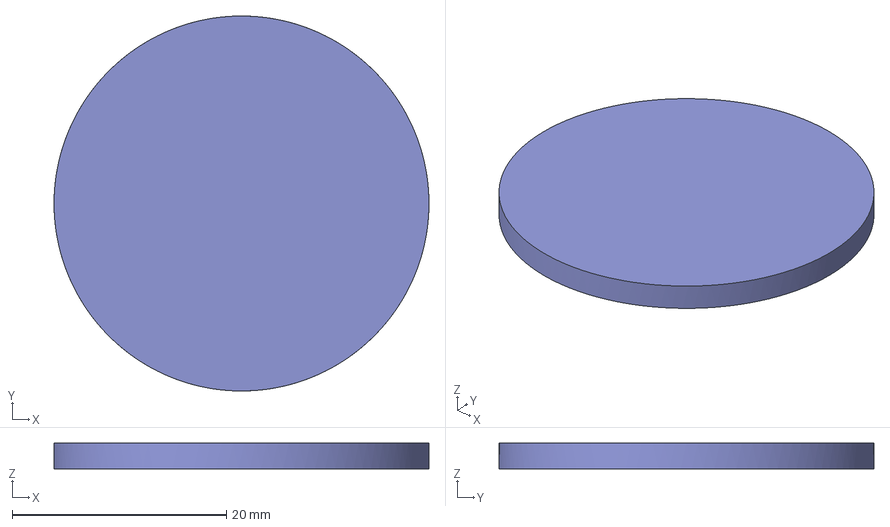
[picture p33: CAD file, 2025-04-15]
modelos/peças_xadrez_3d/Disco 3D.3mf
35.0 x 35.0 x 2.40 mm

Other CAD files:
modelos/peças_xadrez_3d/Base Rainha.3mf

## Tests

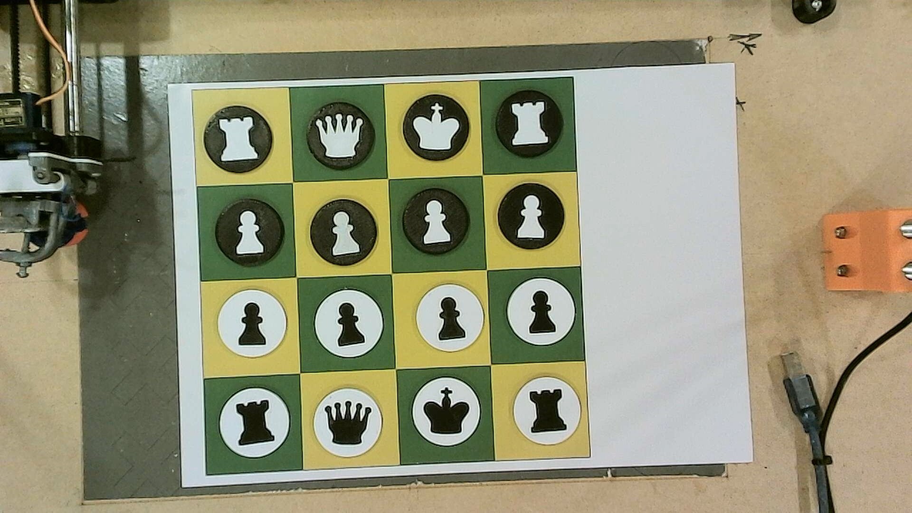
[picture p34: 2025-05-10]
core/cv/assets/storage/testing-chessboards/chessboard_allpieces.jpg

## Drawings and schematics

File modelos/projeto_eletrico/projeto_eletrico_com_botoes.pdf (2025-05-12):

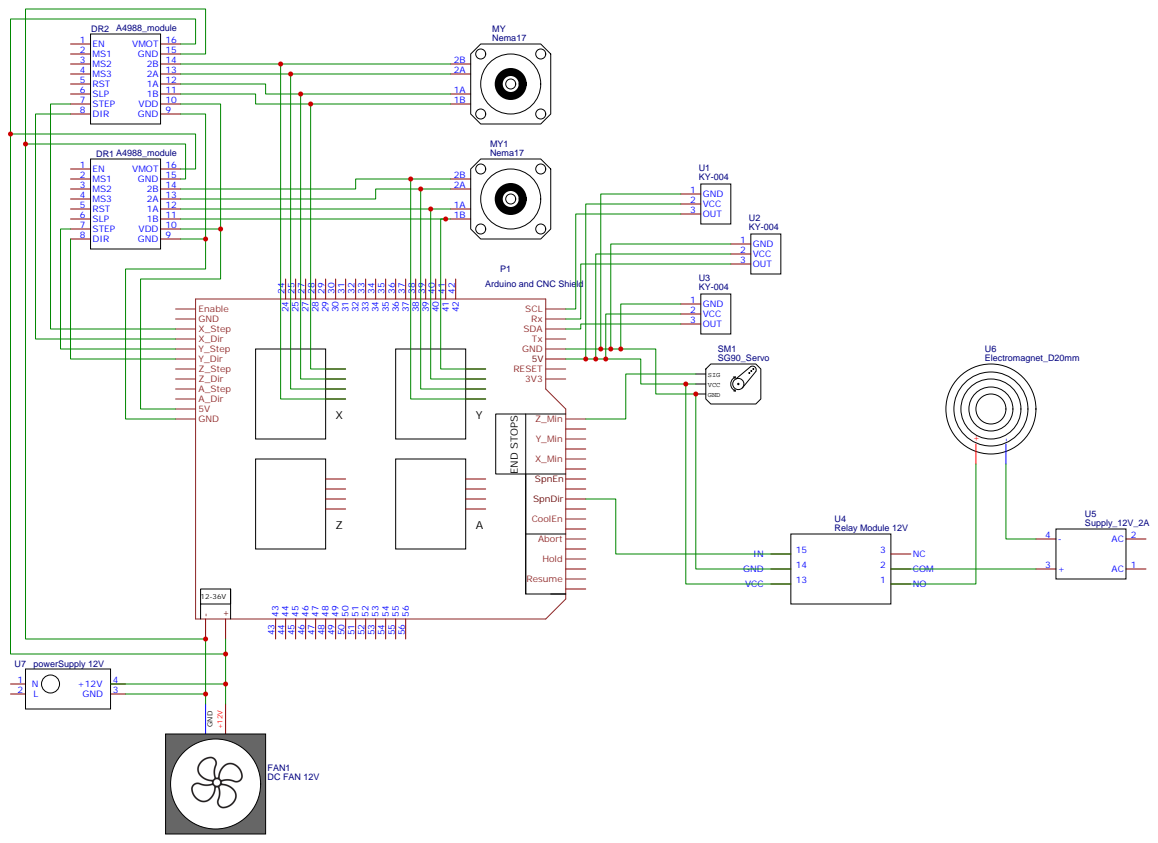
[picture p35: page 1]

Arduino and CNC Shield

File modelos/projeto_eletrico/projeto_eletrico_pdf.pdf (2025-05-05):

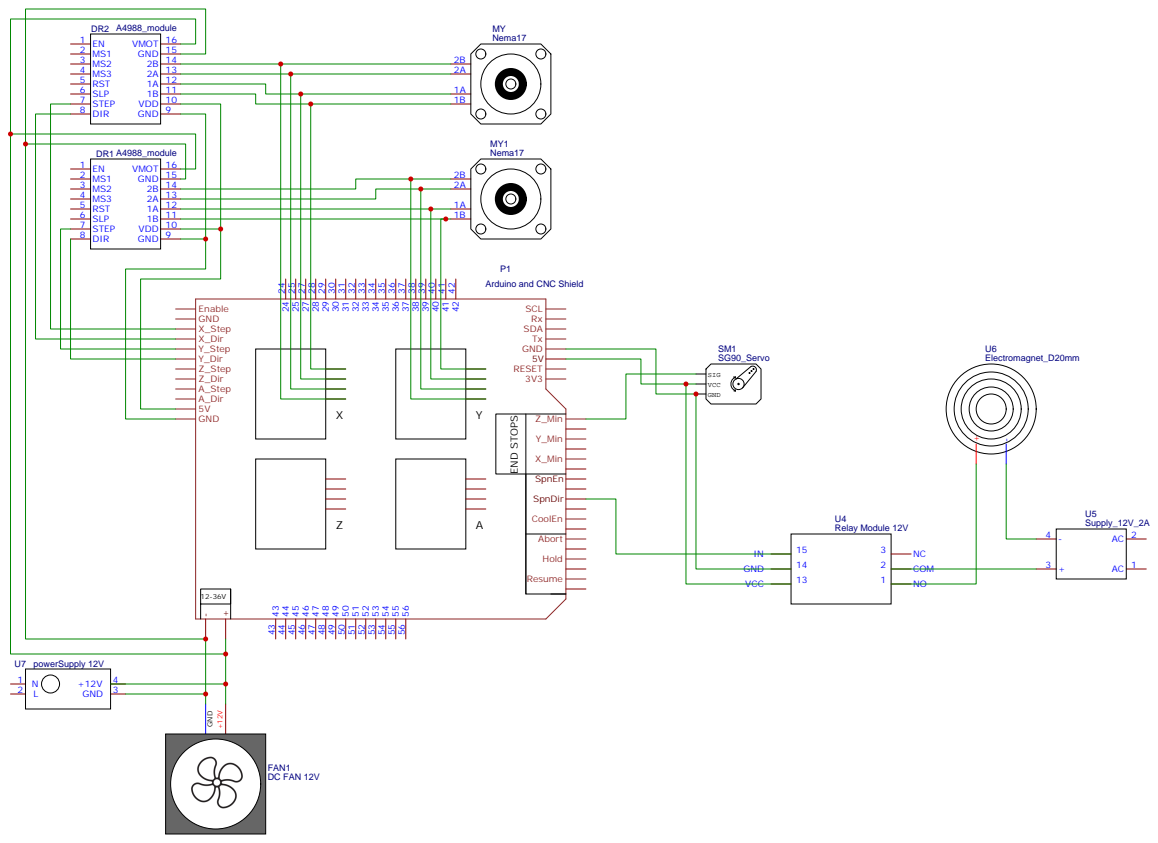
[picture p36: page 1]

Arduino and CNC Shield

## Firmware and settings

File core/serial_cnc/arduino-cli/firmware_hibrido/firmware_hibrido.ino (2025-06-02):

#include <Servo.h>

Servo myServo;
String inputString = "";
boolean stringComplete = false;

// Configurações do servo
const int SERVO_PIN = 11;
const int SERVO_MIN = 0;
const int SERVO_MAX = 180;

// Relé conectado ao SpnDir (pino digital 13)
const int RELAY_PIN = 13;
bool electromagnetState = false;

// Posições do servo
int currentServoPosition = 0;
int targetServoPosition = 0;
const int SERVO_SPEED = 5;  // Reduzido para movimento mais suave
const int SERVO_DELAY = 15; // Aumentado para dar mais tempo entre passos

// Controle de estado do servo
bool servoAttached = false;
bool servoMoving = false;
unsigned long servoLastMoveTime = 0;
const unsigned long SERVO_DETACH_DELAY = 1000; // 1 segundo após parar de mover

// Configurações dos motores de passo
const int STEP_X = 3;
const int DIR_X = 6;
const int STEP_Y = 2;
const int DIR_Y = 5;
const int ENABLE = 8;

long currentX = 0;
long currentY = 0;

const float STEPS_PER_MM = 80.0;
int feedRate = 1500;

void setup() {
  Serial.begin(115200);
  
  // NÃO anexa o servo no início
  pinMode(SERVO_PIN, OUTPUT);
  digitalWrite(SERVO_PIN, LOW); // Garante que o pino está em LOW
  
  pinMode(RELAY_PIN, OUTPUT);
  digitalWrite(RELAY_PIN, LOW);  // Garante que o relé começa desligado

  pinMode(STEP_X, OUTPUT);
  pinMode(DIR_X, OUTPUT);
  pinMode(STEP_Y, OUTPUT);
  pinMode(DIR_Y, OUTPUT);
  pinMode(ENABLE, OUTPUT);
  digitalWrite(ENABLE, HIGH);
  
  Serial.println("Arduino CNC + Servo + Eletroímã Controller");
  Serial.println("Comandos suportados:");
  Serial.println("  G1 X<pos> Y<pos> F<feed> - Movimento linear");
  Serial.println("  G28 - Home (X0 Y0)");
  Serial.println("  G92 X<pos> Y<pos> - Define posição atual");
  Serial.println("  M3 S<valor> - Liga servo (S0-S1000) ou eletroímã (S1)");
  Serial.println("  M4 - Desliga eletroímã");
  Serial.println("  M5 - Desliga servo");
  Serial.println("  ? - Status");
  Serial.println("ok");
  
  inputString.reserve(200);
}

void loop() {
  if (stringComplete) {
    processCommand(inputString);
    inputString = "";
    stringComplete = false;
  }

  // Gerencia movimento do servo de forma otimizada
  manageServoMovement();
}

void manageServoMovement() {
  if (currentServoPosition != targetServoPosition) {
    // Se o servo não estiver anexado, anexa agora
    if (!servoAttached) {
      myServo.attach(SERVO_PIN);
      servoAttached = true;
      delay(50); // Pequeno delay para estabilização
    }
    
    servoMoving = true;
    servoLastMoveTime = millis();
    
    // Movimento mais suave do servo
    int diff = abs(targetServoPosition - currentServoPosition);
    
    if (diff <= SERVO_SPEED) {
      currentServoPosition = targetServoPosition;
    } else {
      currentServoPosition += (currentServoPosition < targetServoPosition) ? SERVO_SPEED : -SERVO_SPEED;
    }
    
    myServo.write(currentServoPosition);
    delay(SERVO_DELAY);
    
  } else if (servoMoving) {
    // Servo chegou na posição final
    servoMoving = false;
    servoLastMoveTime = millis();
  }
  
  // Desanexa o servo após período de inatividade para economizar energia e evitar danos
  if (servoAttached && !servoMoving && 
      (millis() - servoLastMoveTime > SERVO_DETACH_DELAY)) {
    myServo.detach();
    servoAttached = false;
    pinMode(SERVO_PIN, OUTPUT);
    digitalWrite(SERVO_PIN, LOW); // Garante que o pino fica em LOW
  }
}

void serialEvent() {
  while (Serial.available()) {
    char inChar = (char)Serial.read();
    if (inChar == '\n' || inChar == '\r') {
      stringComplete = true;
    } else {
      inputString += inChar;
    }
  }
}

void processCommand(String command) {
  command.trim();
  command.toUpperCase();

  Serial.print("Recebido: ");
  Serial.println(command);

  if (command.startsWith("G1")) {
    float targetX = currentX / STEPS_PER_MM;
    float targetY = currentY / STEPS_PER_MM;

    int xIndex = command.indexOf('X');
    int yIndex = command.indexOf('Y');
    int fIndex = command.indexOf('F');

    if (xIndex >= 0) targetX = extractFloatValue(command, xIndex + 1);
    if (yIndex >= 0) targetY = extractFloatValue(command, yIndex + 1);
    if (fIndex >= 0) feedRate = extractFloatValue(command, fIndex + 1);

    moveToPosition(targetX, targetY);
    Serial.println("ok");
  }

  else if (command.equals("G28")) {
    moveToPosition(0, 0);
    Serial.println("Home completed");
    Serial.println("ok");
  }

  else if (command.startsWith("G92")) {
    int xIndex = command.indexOf('X');
    int yIndex = command.indexOf('Y');
    if (xIndex >= 0) currentX = extractFloatValue(command, xIndex + 1) * STEPS_PER_MM;
    if (yIndex >= 0) currentY = extractFloatValue(command, yIndex + 1) * STEPS_PER_MM;
    Serial.println("Position set");
    Serial.println("ok");
  }

  else if (command.startsWith("M3")) {
    int sValue = extractSValue(command);

    if (sValue == 1) {
      digitalWrite(RELAY_PIN, HIGH);  // Liga eletroímã
      electromagnetState = true;
      Serial.println("Eletroímã ligado");
    } else if (sValue >= 0) {
      targetServoPosition = map(sValue, 0, 1000, SERVO_MIN, SERVO_MAX);
      targetServoPosition = constrain(targetServoPosition, SERVO_MIN, SERVO_MAX);
      Serial.print("Servo para: ");
      Serial.print(targetServoPosition);
      Serial.println(" graus");
    }
    Serial.println("ok");
  }

  else if (command.equals("M4")) {
    digitalWrite(RELAY_PIN, LOW);  // Desliga eletroímã
    electromagnetState = false;
    Serial.println("Eletroímã desligado");
    Serial.println("ok");
  }

  else if (command.equals("M5")) {
    targetServoPosition = SERVO_MIN;
    Serial.println("Servo desligando...");
    // Força o desanexo imediato do servo após chegar na posição
    servoLastMoveTime = millis() - SERVO_DETACH_DELAY - 1;
    Serial.println("ok");
  }

  else if (command.equals("?")) {
    Serial.print("X:");
    Serial.print(currentX / STEPS_PER_MM, 3);
    Serial.print(" Y:");
    Serial.print(currentY / STEPS_PER_MM, 3);
    Serial.print(" Servo:");
    Serial.print(currentServoPosition);
    Serial.print(" graus (");
    Serial.print(servoAttached ? "ATIVO" : "DESCANSO");
    Serial.print(") Eletroímã:");
    Serial.println(electromagnetState ? "LIGADO" : "DESLIGADO");
    Serial.println("ok");
  }

  else {
    Serial.println("ok");
  }
}

void moveToPosition(float targetXmm, float targetYmm) {
  digitalWrite(ENABLE, LOW);

  long targetXsteps = targetXmm * STEPS_PER_MM;
  long targetYsteps = targetYmm * STEPS_PER_MM;
  
  long deltaX = targetXsteps - currentX;
  long deltaY = targetYsteps - currentY;

  digitalWrite(DIR_X, deltaX >= 0 ? HIGH : LOW);
  digitalWrite(DIR_Y, deltaY >= 0 ? LOW : HIGH);

  deltaX = abs(deltaX);
  deltaY = abs(deltaY);

  int stepDelay = calculateStepDelay(feedRate);
  long maxSteps = max(deltaX, deltaY);

  for (long i = 0; i < maxSteps; i++) {
    if (i * deltaX < maxSteps * deltaX) {
      digitalWrite(STEP_X, HIGH); delayMicroseconds(1); digitalWrite(STEP_X, LOW);
    }

    if (i * deltaY < maxSteps * deltaY) {
      digitalWrite(STEP_Y, HIGH); delayMicroseconds(1); digitalWrite(STEP_Y, LOW);
    }

    delayMicroseconds(stepDelay);
  }

  currentX = targetXsteps;
  currentY = targetYsteps;

  Serial.print("Moved to X:");
  Serial.print(targetXmm, 3);
  Serial.print(" Y:");
  Serial.println(targetYmm, 3);
  
  delay(100);
  digitalWrite(ENABLE, HIGH);
}

int calculateStepDelay(int feedRateMMperMin) {
  float stepsPerSec = (feedRateMMperMin * STEPS_PER_MM) / 60.0;
  return (1000000.0 / stepsPerSec);
}

float extractFloatValue(String command, int startIndex) {
  String valueStr = "";
  for (int i = startIndex; i < command.length(); i++) {
    char c = command.charAt(i);
    if (isDigit(c) || c == '.' || c == '-') valueStr += c;
    else break;
  }
  return valueStr.toFloat();
}

int extractSValue(String command) {
  int sIndex = command.indexOf('S');
  if (sIndex >= 0) {
    String sString = command.substring(sIndex + 1);
    for (int i = 0; i < sString.length(); i++) {
      if (!isDigit(sString.charAt(i))) {
        sString = sString.substring(0, i);
        break;
      }
    }
    return sString.toInt();
  }
  return -1;
}

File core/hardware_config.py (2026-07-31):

"""Configuração da montagem física do robô.

Estes valores dependem da câmera, do firmware e da geometria da CNC.
Após qualquer alteração, teste os movimentos sem peças e com o eletroímã
desligado antes de executar uma partida completa.
"""

# Câmera
CAMERA_INDEX = 1
CAMERA_WIDTH = 1920
CAMERA_HEIGHT = 1080
CAMERA_FPS = 30
CAMERA_BUFFER_SIZE = 1
CAMERA_AUTO_EXPOSURE = 0.25
CAMERA_ROTATE_180 = True
CAMERA_BUFFER_FLUSH_FRAMES = 3
CAMERA_CAPTURE_PATH = "assets/current_board.jpg"

# Comunicação serial
SERIAL_PORT = None
SERIAL_BAUDRATE = 115200
SERIAL_TIMEOUT = 1
SERIAL_STARTUP_DELAY = 2
SERIAL_COMMAND_TIMEOUT = 30
SERIAL_RESPONSE_DELAY = 0.1
SERIAL_POLL_INTERVAL = 0.01
SERIAL_PROBE_POLL_INTERVAL = 0.05
SERIAL_PROBE_COMMAND = "?"
SERIAL_FALLBACK_PORTS = (
    "COM3",
    "COM4",
    "COM5",
    "COM6",
    "/dev/ttyUSB0",
    "/dev/ttyUSB1",
    "/dev/ttyACM0",
    "/dev/ttyACM1",
)
FIRMWARE_SIGNATURES = (
    "Servo",
    "Eletroímã",
    "Electromagnet",
    "Arduino CNC",
)

# Arduino dos botões físicos
BUTTONS_SERIAL_PORT = None
BUTTONS_SERIAL_BAUDRATE = 9600
BUTTONS_SERIAL_TIMEOUT = 0.1
BUTTONS_STARTUP_DELAY = 2
BUTTONS_POLL_INTERVAL = 0.01
BUTTON_EVENT_PREFIX = "BUTTON_"

# Comandos aceitos pelo firmware instalado no robô
CNC_INITIALIZATION_COMMANDS = (
    "G21",
    "G90",
    "G92 X0 Y0",
)
SERVO_UP_COMMAND = "S25"
SERVO_DOWN_COMMAND = "S0"
ELECTROMAGNET_ON_COMMAND = "M3"
ELECTROMAGNET_OFF_COMMAND = "M4"

# Movimento e manipulação
CNC_FEED_RATE = 1500
PIECE_HANDLING_DELAY = 1
CNC_NONBLOCKING_MOVE_DELAY = 1
CNC_HOME_POSITION = 0

# Coordenadas absolutas da montagem atual
CNC_POSITIONS = {
    0: (0.000, 0.000),
    1: (16.564, -4.908),
    2: (31.964, -8.988),
    3: (47.500, -13.256),
    4: (63.824, -17.028),
    5: (1.172, -8.844),
    6: (16.332, -13.288),
    7: (30.960, -17.288),
    8: (47.328, -21.020),
    9: (-15.844, -13.008),
    10: (-0.752, -17.700),
    11: (15.984, -20.952),
    12: (31.528, -25.340),
    13: (-32.624, -16.596),
    14: (-15.764, -21.048),
    15: (-0.532, -25.076),
    16: (15.260, -29.476),
    17: (-58.624, -13.596),
    18: (-46.624, -11.096),
    19: (-35.624, -8.096),
    20: (28.260, -36.976),
    21: (39.260, -33.976),
    22: (52.260, -30.976),
}

# Casas 17–19 e 20–22 recebem as peças capturadas
GRAVEYARD_LEFT_START = 17
GRAVEYARD_LEFT_END = 19
GRAVEYARD_RIGHT_START = 20
GRAVEYARD_RIGHT_END = 22

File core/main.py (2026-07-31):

import sys
import os
import ast
from minichess import MiniChess
from ai_player import MiniChessAI
import cv.main as cv
from serial_cnc import cnc_controller
import hardware_config as hardware
import cv2
import time

class OptimizedChessVision:
    """
    Classe para manter estado e otimizar detecção de movimento de xadrez.
    Carrega recursos uma única vez e reutiliza entre chamadas.
    """
    
    def __init__(self):
        self.detector = None
        self.last_board_state = None
        self.board_template = None
        self.calibration_data = None
        self.last_visualization = None
        self._initialize_vision_resources()
    
    def _initialize_vision_resources(self):
        """Inicializa recursos computacionalmente custosos uma única vez."""
        try:
            self.detector = cv2.SIFT_create() if hasattr(cv2, 'SIFT_create') else cv2.ORB_create()
            
            self._load_piece_templates()
            
            print("Recursos de visão computacional inicializados")
        except Exception as e:
            print(f"Erro ao inicializar recursos de visão: {e}")
    
    def _load_piece_templates(self):
        """Carrega templates de peças se disponíveis."""
        templates_dir = "cv/assets/piece_templates"
        if os.path.exists(templates_dir):
            pass
    
    def detect_chess_position_optimized(
        self,
        image_path,
        include_visualization=False,
    ):
        """
        Versão otimizada da detecção que reutiliza recursos.
        """
        if not os.path.exists(image_path):
            print(f"Arquivo não encontrado: {image_path}")
            return None
            
        frame = cv2.imread(image_path)
        
        if frame is None:
            print(f"Não foi possível carregar a imagem: {image_path}")
            return None
        
        try:
            result = cv.detect_chess_position(
                image_path,
                visualize=False,
                save_all=False,
                include_visualization=include_visualization,
            )
            
            if result and "matriz" in result:
                self.last_board_state = result["matriz"]
                self.last_visualization = result.get("visualization")
                return result
            else:
                return None
                
        except Exception as e:
            print(f"Erro na detecção otimizada: {e}")
            return None
    
    def get_board_changes(self, current_matrix):
        """
        Compara com estado anterior para detectar apenas mudanças.
        """
        if self.last_board_state is None:
            return current_matrix
        
        return current_matrix

class OptimizedGameController:
    """
    Controlador de jogo otimizado que mantém estado e recursos.
    """
    
    def __init__(self):
        self.ai_player = None
        self.chess_game = None
        self.controller = None
        self.camera = None
        self.vision_system = OptimizedChessVision()
        self.game_state_cache = {}
        
    def initialize_game_resources(self, use_cnc=True, use_camera=True):
        """Inicializa todos os recursos uma única vez."""
        try:
            os.makedirs('models', exist_ok=True)
            os.makedirs('assets', exist_ok=True)
            
            self.ai_player = MiniChessAI()
            
            if use_cnc:
                self.controller = cnc_controller.CNCArduinoController()
            
            if use_camera:
                self.camera = self._initialize_camera()
            
            self.chess_game = MiniChess(ignore_check_rule=True)
            
            return True
            
        except Exception as e:
            print(f"Erro na inicialização: {e}")
            return False
    
    def _initialize_camera(self):
        """Inicializa a câmera com configurações otimizadas."""
        print("Inicializando câmera...")
        cap = cv2.VideoCapture(hardware.CAMERA_INDEX)
        
        if not cap.isOpened():
            print("Erro: Webcam não encontrada.")
            return None
        
        cap.set(cv2.CAP_PROP_FRAME_WIDTH, hardware.CAMERA_WIDTH)
        cap.set(cv2.CAP_PROP_FRAME_HEIGHT, hardware.CAMERA_HEIGHT)
        cap.set(cv2.CAP_PROP_FPS, hardware.CAMERA_FPS)
        
        cap.set(cv2.CAP_PROP_BUFFERSIZE, hardware.CAMERA_BUFFER_SIZE)
        cap.set(cv2.CAP_PROP_AUTO_EXPOSURE, hardware.CAMERA_AUTO_EXPOSURE)
        
        print("Câmera inicializada com sucesso!")
        return cap
    
    def capture_and_detect_move_optimized(self, include_visualization=False):
        """
        Versão otimizada da captura e detecção de movimento.
        """
        if self.camera is None or not self.camera.isOpened():
            print("Erro: Câmera não está disponível.")
            return None
        
        print("Capturando foto do tabuleiro...")
        
        for _ in range(hardware.CAMERA_BUFFER_FLUSH_FRAMES):
            ret, frame = self.camera.read()
            if not ret:
                break
        
        ret, frame = self.camera.read()
        if not ret:
            print("Erro ao capturar foto da webcam.")
            return None
        
        if hardware.CAMERA_ROTATE_180:
            frame = cv2.rotate(frame, cv2.ROTATE_180)
        
        image_path = hardware.CAMERA_CAPTURE_PATH
        cv2.imwrite(image_path, frame)
        print("Foto do tabuleiro capturada e salva!")

        result = self.vision_system.detect_chess_position_optimized(
            image_path,
            include_visualization=include_visualization,
        )
        
        if result is None or "matriz" not in result or result["matriz"] is None:
            print("Falha ao detectar o tabuleiro. Verifique a imagem e tente novamente.")
            return None

        move_matrix = result["matriz"]

        print("Matriz Identificada:")
        try:
            for i in range(4):
                for j in range(4):
                    print(move_matrix[i][j], end=" ")
                print("")
        except Exception as e:
            print(f"Erro ao imprimir matriz: {e}")
            return None
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

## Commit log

2025-04-11 adicionado diretório para proposta / tarefa 0
2025-04-15 adicionado modelo 3d inicial
    [Disco 3D.3mf]
2025-04-16 adicionados modelos 3d das peças do xadrez
    [Base Peão.3mf, Base Rainha.3mf, Base Rei.3mf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]
2025-04-24 Revert "adicionados modelos 3d das peças do xadrez"
    This reverts commit c980a3ad35863e4eb2da2d2b9f406937699bfb33.
    [Base Peão.3mf, Base Rainha.3mf, Base Rei.3mf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]
2025-04-24 Revert "ia minichess_ia melhorada e minichess_cam-ia modificado"
    This reverts commit c3cf96b515fd498ac9c92e41c65599be358ab057.
    [ai_player.py, main.py]
2025-04-24 adicionados modelos 3d das peças
    [Base Peão.3mf, Base Rainha.3mf, Base Rei.3mf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]
2025-04-24 Diminui a quantidade de prints
2025-04-24 adiciona botão de novo jogo
2025-04-28 adicionado repositório para proposta inicial e proposta revisada
2025-04-28 atualizada estrutura de diretório do modelos_3d
    [Base Peão.3mf, Base Rainha.3mf, Base Rei.3mf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]
2025-04-29 adicionados os modelos de tabuleiro
    [Base Peão.3mf, Base Rainha.3mf, Base Rei.3mf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]
2025-04-30 deixa só um gitignore para que tenha um só venv no projeto
2025-05-07 cv: update
    [Base Peão.3mf, Base Rainha.3mf, Base Rei.3mf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]
2025-05-07 corrigida a identificação das cores
    [main.py]
2025-05-08 atualiza o reference path para anular o erro
2025-05-10 start serial arduino communication
2025-05-12 Adicionando link para modelo 3d
2025-05-12 adicionando arquivo .stl modelo 3d
2025-05-16 modifica o cv para retornar uma matriz
2025-05-17 arruma o path do modelo de IA (tira minichessia2)
2025-05-18 cria um modo cli funcional do minichess para integração com cv
2025-05-18 versão de teste do cv
2025-05-23 Adicionando interprete movimento da ia para movimento da cnc
2025-06-02 tira o arduino-cli do repo
2025-06-05 adiciona lógica de posições de morte
2025-06-05 core: faz com que o controlador CNC não seja iniciado todas as vezes
2025-06-13 otimizacoes de tempo
2025-06-14 adicionado script para botoes pyserial
2025-06-14 tira a necessidade de clicar enter
2025-06-21 adicionado diretorio da apresentacao + refatorado estrutura de pastas do minichess
2025-06-24 atualizados diretórios de apresentacao e artigo
2025-06-24 atualizada topologia de diretórios do projeto
2026-07-21 feat(cnc): auto-detect serial port for Arduino/CNC controller
2026-07-22 feat(cnc): identify CNC Arduino by firmware response signature
2026-07-22 fix(cv): improve board detection, piece color and type recognition
    - detect_board_corners: score quadrilaterals by square aspect ratio to avoid
    picking the whole image frame
    - piece_detection: use disk-vs-square-background contrast and add contour fallback
    - piece_recognition_sift: add grayscale template matching fallback with
    color-aware inversion
    - cv/main: allow --save-all to work without visualization
    [main.py]
2026-07-31 add new board captures
2026-07-31 strengthen experienced AI king safety
    [ai_player.py, test_ai.py]
